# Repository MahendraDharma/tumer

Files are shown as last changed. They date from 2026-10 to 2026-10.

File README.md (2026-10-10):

# Jig Assembly ragum

| File | Isi |
|---|---|
| `Ver3 Jig Assembly ragum tetap.step` | Versi asli: hanya piringan hitam yang berputar, ragum dibaut ke Base |
| `Ver4 Jig Assembly ragum putar.step` | Versi baru: ditambah **Piringan bawah** sehingga kedua ragum ikut berputar |
| `Ver4 Jig + TBU terjepit.step` | Ver4 dengan TBU (model sederhana) dalam kondisi terjepit kedua ragum |
| `tools/tambah_piringan_bawah.py` | Script yang membuat Ver4 dari Ver3 (`pip install cadquery`, lalu `python3 tools/tambah_piringan_bawah.py`) |

## Perubahan Ver3 → Ver4

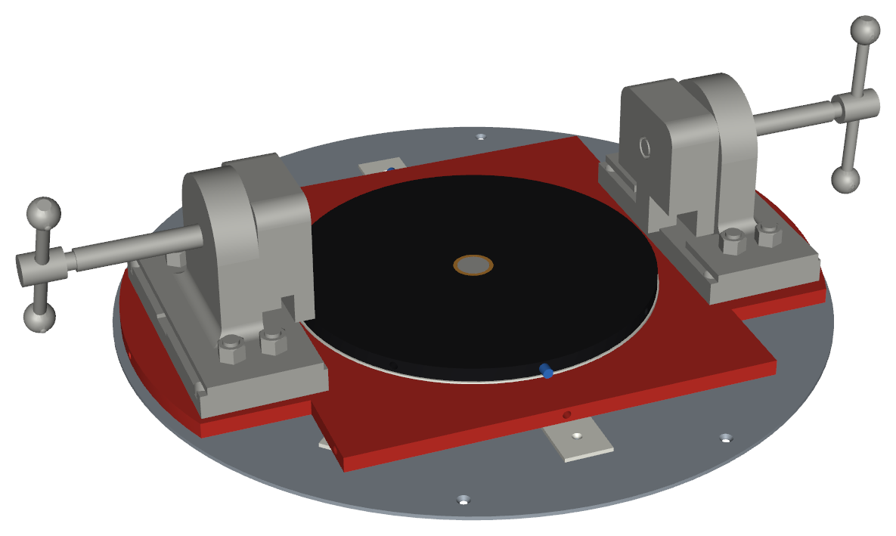
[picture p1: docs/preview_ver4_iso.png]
Pratinjau Ver4 (piringan bawah merah, pin biru; warna hanya di gambar ini)


Bagian baru dirampingkan ke faktor keamanan ≥ 2 (spesifikasi kelompok). Susunan dari bawah ke atas (satuan mm):

1. **Base (rev)** – plat bulat SS400 Ø900 × 5 yang menutup seluruh area putar, ditopang penuh oleh meja kerja dan diikat dengan **8 baut kepala benam M8** (rata permukaan, mur di bawah meja). Ada 4 tap M6 untuk ring UHMW, 4 tap M6 untuk flens Pin center, dan 8 tap M6 untuk bantalan UHMW.
2. **Ring UHMW** – Ø464 / Ø300 × 5, di atas Base, 4 baut L M6 kepala tenggelam.
   **8 Bantalan UHMW** – 70 × 60 × 5 di r ≈ 330 (tiap 45°), di bawah ujung piringan bawah tempat ragum, jadi ragum tidak mengambang. Setiap bantalan diikat 1 baut benam M6.
3. **Piringan bawah** (baru) – plat SS400 20 mm, lingkaran Ø880 dipangkas menjadi lajur 600 mm sepanjang sumbu ragum; di bawah dudukan (lebih dari 270 mm dari sumbu) lebarnya 360 mm (±65 kg).
   - Lubang Ø50 di tengah untuk **Bushing perunggu bawah** (Ø50/Ø40,1 × 15), cekungan bawah Ø86 × 2 di atas flens Pin center, dan cekungan Ø62 × 3 untuk thrust bearing bawah.
   - Cekungan Ø465 × 1 di muka atas untuk **Ring UHMW atas** (Ø464 / Ø300 × 3).
   - 8× tap M12 untuk baut kedua **Dudukan ragum** (pola sama dengan Base Ver3).
   - 8× lubang radial Ø10,5 (tiap 45°) dari tepi sampai lubang tengah, untuk Pin index bawah.
4. **Piringan (baru)** (piringan utama), bushing, Pin index + knob, kedua ragum beserta stud, mur, vise holder, clamp, rod dan handle – **naik 10 mm** terhadap Ver3, posisi XZ tidak berubah. Jarak rahang ragum ke piringan utama sama seperti Ver3. Piringan utama diberi cekungan Ø62 × 1 di muka bawah untuk thrust bearing atas, dan bushing-nya dipendekkan 1 mm (Ø50/Ø40,1 × 17).
5. Alas TBU (muka atas piringan utama) berada **50 mm** di atas meja kerja, sesuai REQ-02 (≤ 50 mm).

### Bearing

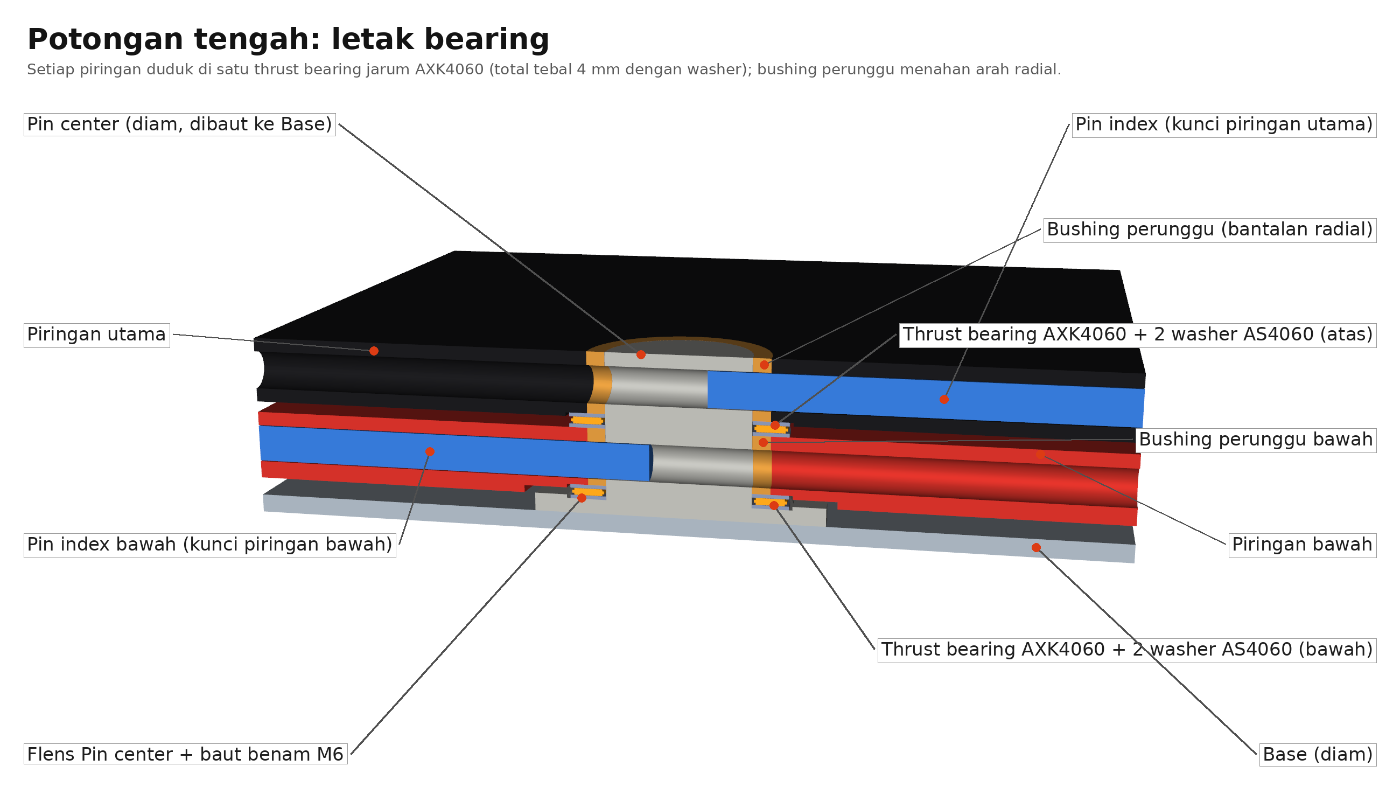
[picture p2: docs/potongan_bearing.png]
Potongan tengah: letak bearing


Setiap piringan berputar di atas satu **thrust bearing jarum AXK4060** (d40 × D60 × 2) yang diapit 2 **washer AS4060** (1 mm), jadi tebal satu set 4 mm. **Bushing perunggu** menahan arah radial.
- **Set bawah**: dibenamkan 1 mm di flens Pin center (diam) dan menopang piringan bawah. Baut flens diganti baut benam M6 supaya rata di bawah washer.
- **Set atas**: di cekungan atas piringan bawah dan menopang piringan utama.

Bearing bola 51108 (tinggi 13 mm) dan 6008 (lebar 15 mm) tidak dipakai: keduanya hanya muat kalau jig dinaikkan atau pin pengunci, yang lewat di tengah tebal plat, dipindahkan. Ring dan bantalan UHMW tetap menopang bagian luar piringan.

### Kunci samping (kedua piringan)

Pin masuk dari tepi piringan, lurus ke tengah, dan ujungnya masuk ±12 mm ke lubang silang di **Pin center** yang diam. Tarik pin ±20 mm agar piringan bisa diputar; kunci di 0° dan 180° (lihat catatan posisi kunci di bawah).

- **Piringan utama**: **Pin index (panjang)** = Pin index asli yang diperpanjang ke dalam; knob tetap di tempatnya.
- **Piringan bawah**: **Pin index bawah** (batang Ø10) + **Knob pin index bawah** (salinan knob asli) di sisi −X.
- **Pin center (panjang)**: flens dibaut ke Base; poros Ø40 sampai rata muka atas piringan utama, 2 lubang silang Ø10,5.

### Faktor keamanan (target ≥ 2)

| Bagian | Beban penentu | n |
|---|---|---|
| Piringan bawah, potongan tengah (melewati lubang pin, Ø50, dan cekungan bearing) | Momen jepit ragum F<sub>c</sub>·h = 10 829 N × 210 mm (momen penuh, konservatif) | 2,6 |
| Piringan bawah, awal bagian 360 mm (z = 275) | Momen jepit penuh (konservatif) | 2,5 |
| Piringan bawah, potongan lain | Sama | > 3,2 |
| Ulir M12 dudukan di piringan bawah (plat 20, ulir terpakai 18) | Tarik baut dari momen guling + preload | 3,9 |
| Baut M12 dudukan | Sama; momen kencang dibatasi 37 N·m | ±3 |
| Baut flens Pin center M6 (geser) | Torsi kerja 210 N·m saat terkunci | 3,4 |
| Base 5 mm, ring dan bantalan UHMW 5/3 mm, bushing 15/17 mm | Berat; ditopang meja | > 4 |
| Thrust bearing AXK4060 | Berat piringan + TBU (< 1,5 kN per bearing) | jauh di atas kebutuhan |

Berat total jig (tanpa TBU dan meja): ±188 kg.

Hasil pengecekan CAD: celah pin–lubang 0,25 mm, pin center–bushing 0,05 mm, flens Pin center–piringan bawah 2 mm, pin–washer bearing ≥ 2 mm, knob pin bawah–bantalan 3,6 mm; tidak ada tumpang tindih antar part.

## Catatan

- Base Ø900 menjorok ±41 mm keluar dari tepi meja kerja di sisi +Z.
- Baut Base ke meja diubah dari 4 × M20 (REQ-05) menjadi 8 × M8 kepala benam, karena kepala M20 akan tertabrak piringan bawah.
- Dudukan ragum, vise holder, dan clamp adalah part Ver3 dan tidak diubah. Piringan utama (18 mm) hanya ditambah cekungan bearing Ø62 × 1.

## Cara penggunaan (visualisasi dengan TBU)

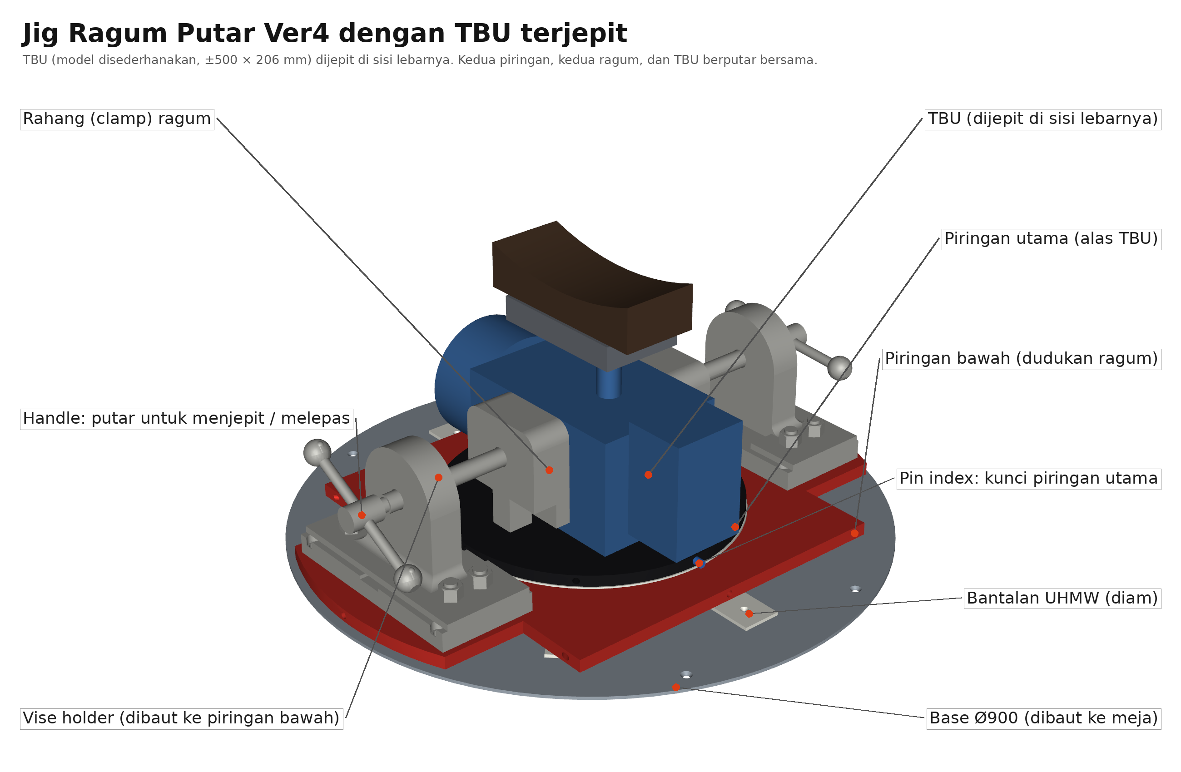
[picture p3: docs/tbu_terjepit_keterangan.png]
Jig dengan TBU terjepit


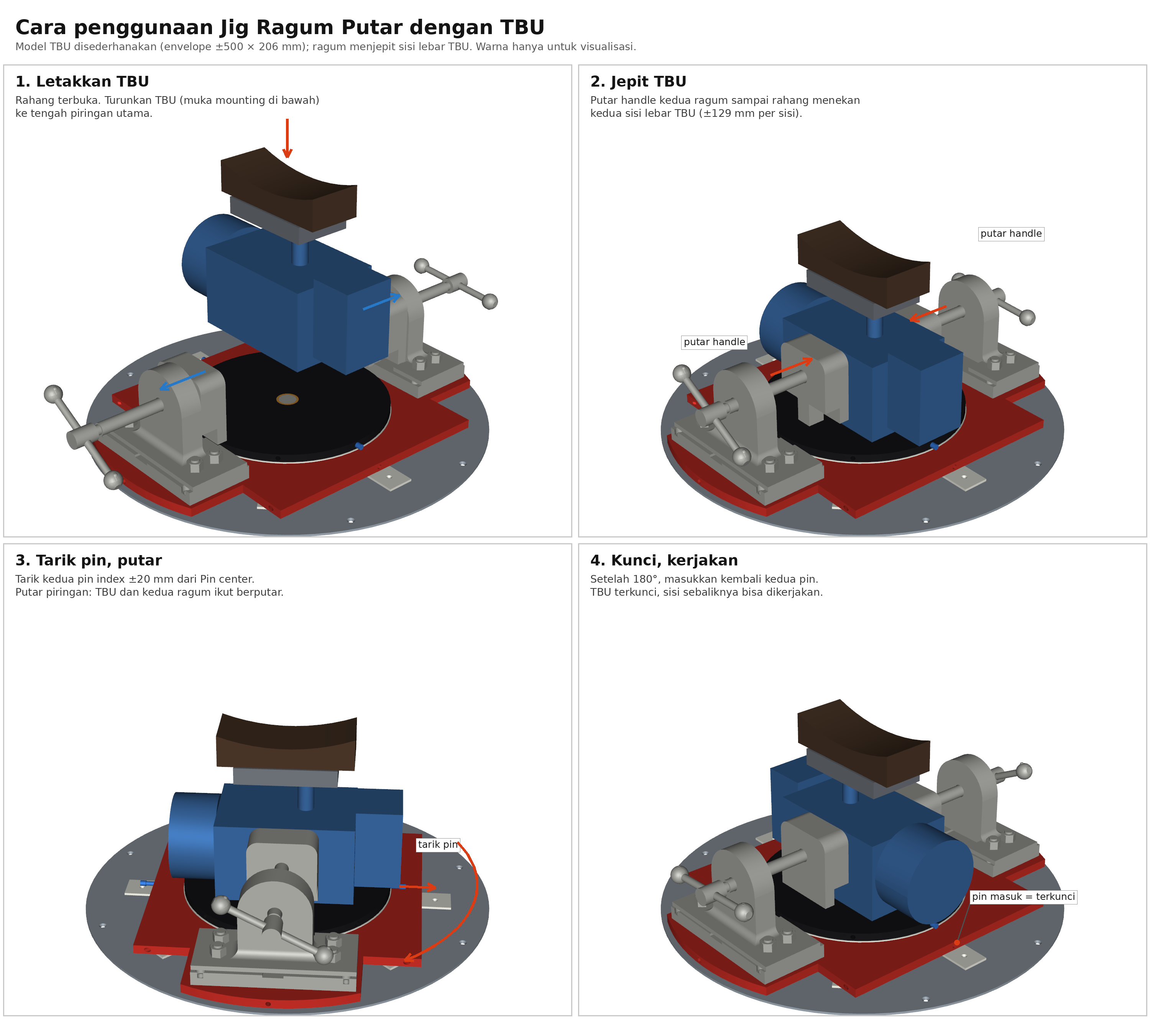
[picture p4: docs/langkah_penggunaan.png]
Langkah penggunaan


1. Buka kedua rahang. Letakkan TBU dengan muka mounting (4 × M20) di bawah, di tengah piringan utama, dengan sisi panjangnya melintang terhadap sumbu ragum.
2. Putar handle kedua ragum sampai rahang menekan kedua sisi lebar TBU. Untuk lebar ±206 mm, setiap rahang maju ±129 mm. T-handle perlu diposisikan mendatar di akhir langkah; kalau menghadap ke bawah, ia menabrak dudukan ragum (bebas sampai langkah ±115 mm).
3. Tarik kedua pin index ±20 mm dari Pin center, lalu putar piringan. TBU, kedua ragum, dan kedua piringan berputar bersama.
4. Setelah 180°, masukkan kembali kedua pin. TBU terkunci dan sisi sebaliknya bisa dikerjakan.

Model TBU disederhanakan (envelope ±500 × 206 mm, pola mounting 114 × 250 dari gambar Nabtesco 152-3.5), bukan geometri asli. Kedua ragum di Ver3 terpasang miring ±0,82° terhadap sumbu jig, jadi TBU di model diputar dengan sudut yang sama. Dibuat dengan `tools/visualisasi_tbu.py` (STEP) dan `tools/render_visualisasi_tbu.py` (gambar).

**Catatan posisi kunci:** saat ini kedua pin hanya bisa mengunci di 0° dan 180°.
- Pin index bawah (panjang 292 mm) hanya cocok di arah lajur ±X. Di sudut lain, tepi piringan bawah lebih jauh dari pusat (424–440 mm), sehingga pin dan knob tertanam di plat.
- Piringan utama Ver3 tidak punya lubang radial tembus di salah satu arah 90°.

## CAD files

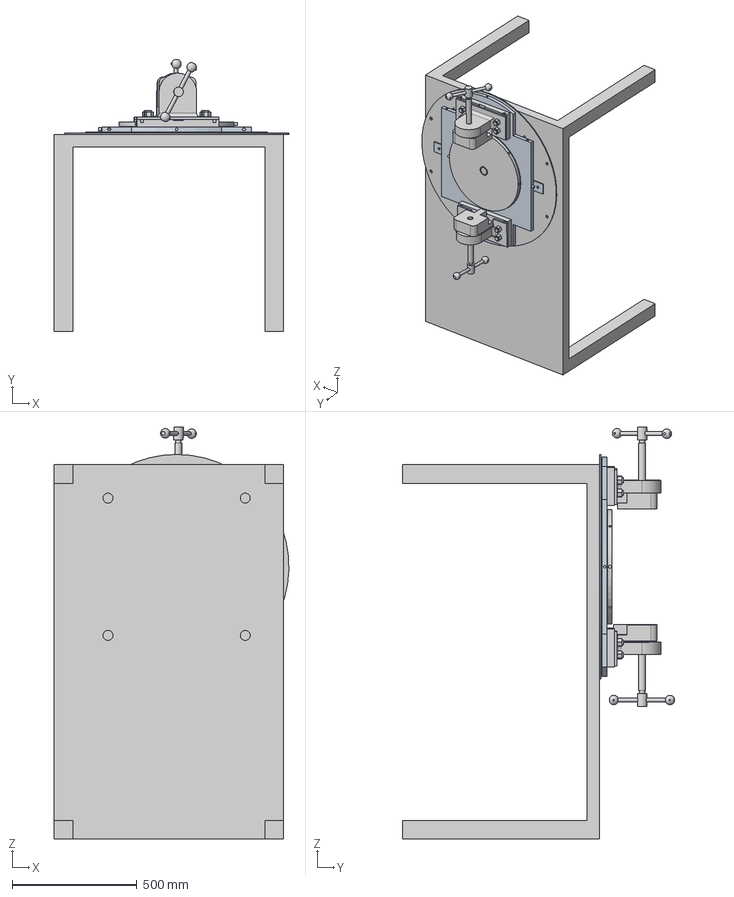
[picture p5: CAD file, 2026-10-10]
Ver4 Jig Assembly ragum putar.step
940.8 x 1089.6 x 1650.7 mm
Knob pin index
Dudukan ragum atas
Dudukan ragum bawah
Stud M20 1
Stud M20 2
Stud M20 3
Stud M20 4
Stud M20 5
Stud M20 6
Stud M20 7
Stud M20 8
Vise Holder atas
Mur M20 5
Mur M20 6
Mur M20 7
Mur M20 8
Clamp self made atas
Vise Rod atas
Handle mil atas
Handle pim atas
Handle top atas
Handle pim atas001
Handle top atas001
Vise Holder bawah
Mur M20 1
Mur M20 2
Mur M20 3
Mur M20 4
Clamp self made bawah
Vise Rod bawah
Handle mil bawah
Handle pim bawah
Handle top bawah
Handle pim bawah001
Handle top bawah001
Replika workbench
Pin center (panjang)
Piringan (baru)
Bushing perunggu
Pin index (panjang)
Ring UHMW
Ring UHMW atas
Piringan bawah
Bushing perunggu bawah
Washer AS4060 bawah 1
Thrust bearing AXK4060 bawah
Washer AS4060 bawah 2
Washer AS4060 atas 1
Thrust bearing AXK4060 atas
Washer AS4060 atas 2
Pin index bawah
Knob pin index bawah
Base (rev)
Bantalan UHMW 1
Bantalan UHMW 2
Bantalan UHMW 3
Bantalan UHMW 4
Bantalan UHMW 5
Bantalan UHMW 6
Bantalan UHMW 7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

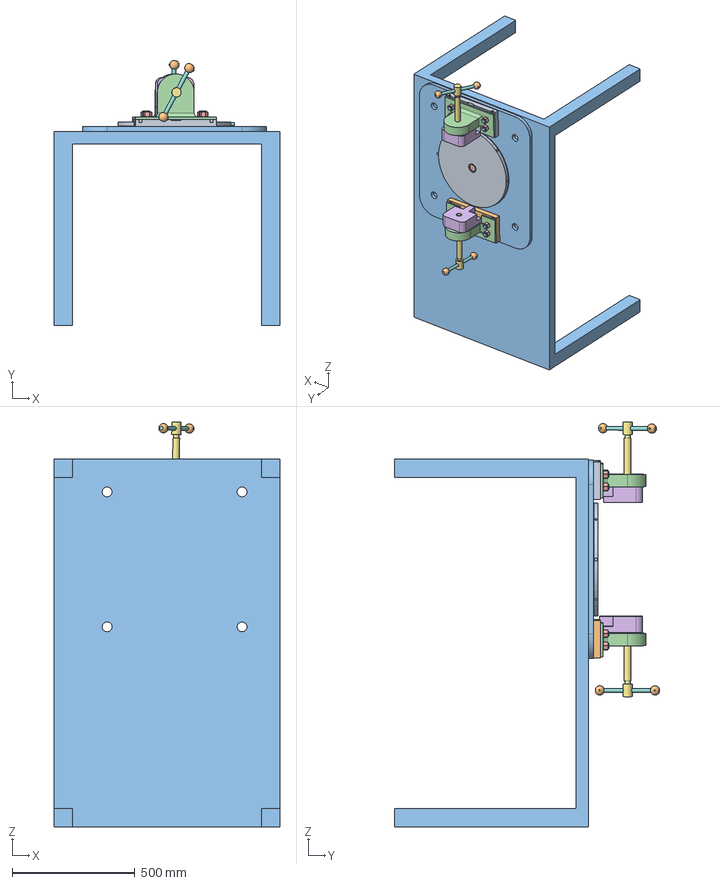
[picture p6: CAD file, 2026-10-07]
Ver3 Jig Assembly ragum tetap.step
920.0 x 1079.6 x 1650.7 mm
Piringan (baru)
Bushing perunggu
Base (rev)
Ring UHMW
Pin center
Pin index
Knob pin index
Dudukan ragum atas
Dudukan ragum bawah
Stud M20 1
Stud M20 2
Stud M20 3
Stud M20 4
Stud M20 5
Stud M20 6
Stud M20 7
Stud M20 8
Vise Holder atas
Mur M20 5
Mur M20 6
Mur M20 7
Mur M20 8
Clamp self made atas
Vise Rod atas
Handle mil atas
Handle pim atas
Handle top atas
Handle pim atas001
Handle top atas001
Vise Holder bawah
Mur M20 1
Mur M20 2
Mur M20 3
Mur M20 4
Clamp self made bawah
Vise Rod bawah
Handle mil bawah
Handle pim bawah
Handle top bawah
Handle pim bawah001
Handle top bawah001
Replika workbench

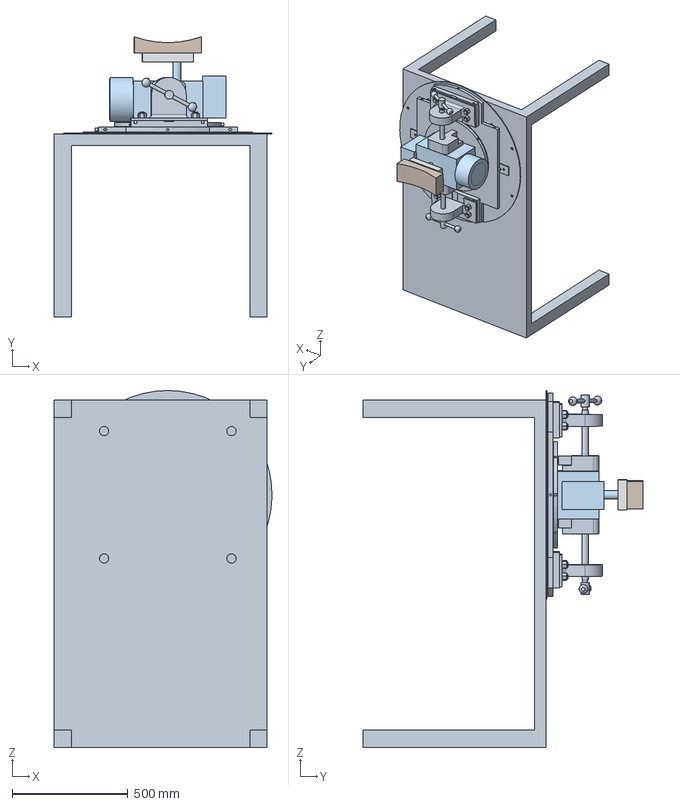
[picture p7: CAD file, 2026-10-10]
Ver4 Jig + TBU terjepit.step
940.8 x 1210.2 x 1540.8 mm
Knob pin index
Dudukan ragum atas
Dudukan ragum bawah
Stud M20 1
Stud M20 2
Stud M20 3
Stud M20 4
Stud M20 5
Stud M20 6
Stud M20 7
Stud M20 8
Vise Holder atas
Mur M20 5
Mur M20 6
Mur M20 7
Mur M20 8
Clamp self made atas
Vise Rod atas
Handle mil atas
Handle pim atas
Handle top atas
Handle pim atas001
Handle top atas001
Vise Holder bawah
Mur M20 1
Mur M20 2
Mur M20 3
Mur M20 4
Clamp self made bawah
Vise Rod bawah
Handle mil bawah
Handle pim bawah
Handle top bawah
Handle pim bawah001
Handle top bawah001
Replika workbench
Pin center (panjang)
Piringan (baru)
Bushing perunggu
Pin index (panjang)
Ring UHMW
Ring UHMW atas
Piringan bawah
Bushing perunggu bawah
Washer AS4060 bawah 1
Thrust bearing AXK4060 bawah
Washer AS4060 bawah 2
Washer AS4060 atas 1
Thrust bearing AXK4060 atas
Washer AS4060 atas 2
Pin index bawah
Knob pin index bawah
Base (rev)
Bantalan UHMW 1
Bantalan UHMW 2
Bantalan UHMW 3
Bantalan UHMW 4
Bantalan UHMW 5
Bantalan UHMW 6
Bantalan UHMW 7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

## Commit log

2026-10-07 Tambah piringan bawah agar ragum ikut berputar (Ver4)
    Piringan bawah Ø880x20 ditambahkan di antara Base dan piringan utama,
    menumpang di Ring UHMW asli dan berputar pada Pin center yang
    diperpanjang. Kedua dudukan ragum dan seluruh tumpukan atas naik 22 mm.
    Ver4 dibuat dari Ver3 oleh tools/tambah_piringan_bawah.py.
    Claude-Session: https://claude.ai/code/session_01E1QDrkaZbRDzJGHvCXX9P5
    [Ver4 Jig Assembly ragum putar.step]
2026-10-07 Tambah pengunci dan penopang luar untuk piringan bawah
    Base (rev2) mendapat kantong Ring UHMW luar (Ø710/Ø610) sebagai penopang
    kedua dan 8 lubang index Ø16 tiap 45°. Pin index bawah Ø16 lewat Blok
    pin index bawah di sisi -X mengunci piringan bawah ke Base.
    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
    [Ver4 Jig Assembly ragum putar.step]
2026-10-07 Revert "Tambah pengunci dan penopang luar untuk piringan bawah"
    This reverts commit cd8680591bf6ee703c86c3c0f768e6c1fcd0c542.
    [Ver4 Jig Assembly ragum putar.step]
2026-10-07 Pertahankan nama root assembly JigTBU_rev2 dari Ver3
    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
    [Ver4 Jig Assembly ragum putar.step]
2026-10-07 Tambah kunci samping piringan bawah dan perlebar Base ke sisi -X
    Pin index bawah (salinan Pin index) masuk horizontal ke 8 lubang radial
    di tepi piringan bawah, ditahan blok di Base yang diperlebar.
    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
    [Ver4 Jig Assembly ragum putar.step]
2026-10-07 Kunci kedua piringan dari samping ke Pin center, Base 920x920
    Blok kunci di Base dihapus. Pin index (diperpanjang) dan Pin index bawah
    masuk radial sampai lubang silang di Pin center. Piringan bawah 30 mm
    agar lubang pin muat di bawah kantong ring; tumpukan atas naik 32 mm.
    Base diperlebar menjadi 920x920 R100 agar piringan bawah tertumpu penuh.
    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
    [Ver4 Jig Assembly ragum putar.step]
2026-10-09 Base jadi plat 5 mm tanpa kantong, ditopang meja kerja
    Ring UHMW duduk di atas Base, sehingga semua part di atas Base turun 5 mm.
    Base hanya menyisakan 4 lubang Ø40 ke meja dan 8 tap M6 (ring UHMW dan
    flens Pin center). Nama part Knob pin index bawah di STEP diperbaiki.
    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
    [Ver4 Jig Assembly ragum putar.step]
2026-10-09 Rampingkan bagian baru ke faktor keamanan ±3
    Piringan bawah jadi plat 20 mm berbentuk lajur 700 mm (127 -> 81 kg),
    ring UHMW 5 mm dan 3 mm, bushing bawah 18 mm. Tumpukan turun sehingga
    alas TBU tepat 50 mm di atas meja (REQ-02).
    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
    [Ver4 Jig Assembly ragum putar.step]
2026-10-09 Rampingkan ke faktor keamanan ±2,5 dan perkecil Base
    Piringan bawah jadi lajur 600 mm dengan ujung 360 mm di bawah dudukan
    (81 -> 65 kg), Base 660x660x5 R60 (33 -> 17 kg). Berat total jig ±179 kg.
    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
    [Ver4 Jig Assembly ragum putar.step]
2026-10-09 Base bulat Ø900 dengan baut benam M8 dan 8 bantalan UHMW di bawah ragum
    Ujung piringan bawah (tempat ragum) kini bertumpu pada bantalan UHMW 5 mm,
    sehingga ragum tidak mengambang. Baut benam M8 rata permukaan, tidak lagi
    tertabrak piringan bawah. Tinggi alas TBU tetap 50 mm.
    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
    [Ver4 Jig Assembly ragum putar.step]
2026-10-09 Piringan bawah 20 -> 19 mm (faktor keamanan minimum 2,2)
    Plat 18 mm hanya mencapai n = 1,87 di potongan tengah (lubang pin dan Ø50),
    jadi 19 mm adalah tebal terkecil dengan n > 2. Alas TBU turun ke 49 mm,
    berat total jig ±184 kg.
    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
    [Ver4 Jig Assembly ragum putar.step]
2026-10-09 Visualisasi cara pakai: TBU terjepit kedua ragum
    Model TBU Nabtesco 152-3.5 yang disederhanakan (300 x 206 mm) dijepit di
    atas piringan utama. Tambah STEP kondisi terjepit dan gambar 4 langkah
    penggunaan (letakkan, jepit, tarik pin dan putar, kunci).
    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
    [Ver4 Jig + TBU terjepit.step]
2026-10-09 Visualisasi: ragum menjepit sisi lebar TBU
    TBU (±500 x 206 mm) kini dijepit di sisi lebarnya; rahang maju ±129 mm
    dan T-handle diposisikan mendatar agar tidak menabrak dudukan ragum.
    Langkah 4 memakai posisi 180°, karena pin saat ini hanya bisa mengunci
    di 0° dan 180° (dicatat di README).
    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
    [Ver4 Jig + TBU terjepit.step]
2026-10-10 Tambah thrust bearing AXK4060 di bawah kedua piringan
    Setiap piringan kini berputar di atas thrust bearing jarum AXK4060 + 2
    washer AS4060 (4 mm), bushing perunggu tetap sebagai bantalan radial.
    Piringan bawah kembali 20 mm (SF 2,47), alas TBU tetap 50 mm. Baut flens
    Pin center jadi baut benam M6. Tambah gambar potongan letak bearing.
    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
    [Ver4 Jig + TBU terjepit.step, Ver4 Jig Assembly ragum putar.step]
2026-10-11 UHMW diberi celah 1 mm agar berat dipikul bearing
    Ring dan bantalan UHMW jadi 4 mm, ring atas 2 mm (celah 1 mm ke piringan).
    Tanpa celah, berat bertumpu pada UHMW dan gaya putar ±360 N; dengan celah
    gaya putar ±22 N (REQ-07 <= 50 N). Baut ring UHMW jadi baut benam M6.
    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
2026-10-15 Model TBU dibuat mengikuti foto TBU asli
    Silinder rem tegak dengan flens dan pipa siku, badan cor miring, lengan
    tuas dengan dua pin, shoe head dengan alur blok rem, tutup bundar,
    nameplate, dan poros penyetel. Celah rahang tetap 0,2 mm, tanpa tabrakan
    pada 0°, 45°, dan 180°. Gambar visualisasi dirender ulang.
    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
